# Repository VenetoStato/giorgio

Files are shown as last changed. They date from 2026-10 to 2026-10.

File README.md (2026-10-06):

<div align="center">

# GIORGIO

**An open, mobile two-armed service robot. It sorts, carries, docks to charge itself, and makes espresso.**

*We couldn't build the parts. So we bought them, and made them work together.*








<a href="https://github.com/VenetoStato/giorgio/releases/download/v0.1.0-design/giorgio_teaser.mp4">
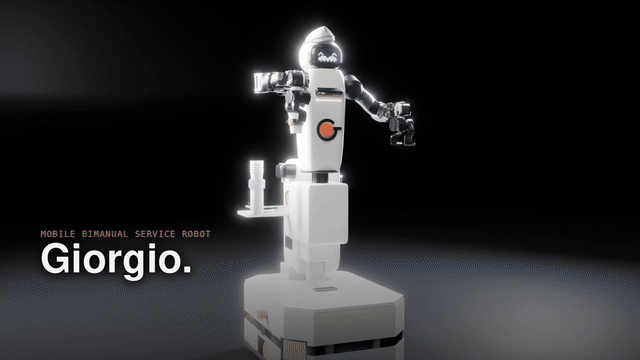
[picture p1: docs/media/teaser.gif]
Giorgio teaser: the robot picks parts, sorts them by colour and drives to the next station (simulation render)
  
</a>

<sub>Simulation render. Click the GIF for the full 68 s teaser. <a href="#videos">More videos ↓</a></sub>

</div>

> [!IMPORTANT]
> **Work in progress: design and simulation only.** Giorgio has **not been built**. Many points are still open:
> type tests, CE certification, the choice of arms, real-hardware validation and more.
> See [Known gaps & open questions](#known-gaps--open-questions). Every number in this repository comes either from
> a manufacturer document or is marked as an estimate or an assumption. Help is very welcome.

Giorgio is a mobile bimanual service robot assembled from **open-hardware projects and certified off-the-shelf
components**:
- Enactic **OpenArm 2.0** arms;
- our own AMR base, built from a SICK, Pilz and ez-Wheel safety chain;
- an Orbbec depth camera and an NVIDIA Jetson.

The structure, shells, power system and software are our own. All of it is public: CAD, calculations, electrical and
safety design, a CE technical-file skeleton, a MuJoCo simulation of the whole robot, the robot software
(GIORGIO-OS) and reinforcement-learning training. Fork it, study it, improve it.

## Contents
[Start here](#start-here) · [What it does](#what-it-does) · [Videos](#videos) · [Architecture](#architecture) ·
[Repository map](#repository-map) · [Quick start](#quick-start) · [Bill of materials](#bill-of-materials) ·
[Customise](#customise-your-giorgio) · [Contribute](#how-to-contribute) · [Known gaps](#known-gaps--open-questions) ·
[Roadmap](#roadmap) · [Status & honesty](#status--honesty) · [Licence](#licence) · [Trademarks](#trademarks)

## Start here

| I want to… | Go to | Time |
|---|---|---|
| **Just look** | the [videos](#videos), the [AMR base datasheet](https://github.com/VenetoStato/giorgio/releases/download/v0.1.0-design/giorgio_amr_datasheet.html) (download it and open it in a browser), the renders in [`amr/renders/`](amr/renders/web) and the [bill of materials](docs/BOM_OVERVIEW.md) | 5 min |
| **Run the simulation** | [Quick start](#quick-start): `make setup && make sim` | 5–10 min |
| **Change the design** | [Customise your Giorgio](docs/CUSTOMIZE.md), then [CONTRIBUTING.md](CONTRIBUTING.md). Starter tasks are labelled [good first issue](https://github.com/VenetoStato/giorgio/labels/good%20first%20issue) | an evening |

Questions and ideas go to [Discussions](https://github.com/VenetoStato/giorgio/discussions). Some file and variable
names are still in Italian; the [glossary](docs/GLOSSARY.md) translates them.

## What it does

All clips are renders of the **MuJoCo simulation** (Blender 4.5 over recorded physics states), not footage of hardware.

<table>
<tr>
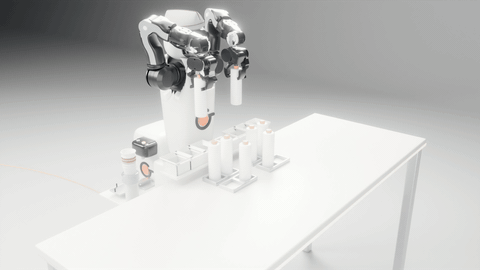
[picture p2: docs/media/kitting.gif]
Kitting: Giorgio loads bottles into its own tray
<td width="33%"><br><b>Kitting.</b> It loads its own tray and uses vision to insert the parts into the kit.</td>
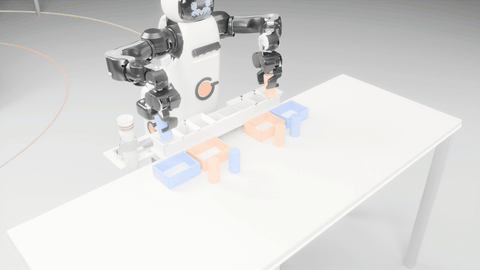
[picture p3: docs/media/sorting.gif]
Sorting parts by colour
<td width="33%"><br><b>Sorting.</b> It sorts parts by colour with a clash-aware two-arm planner.</td>
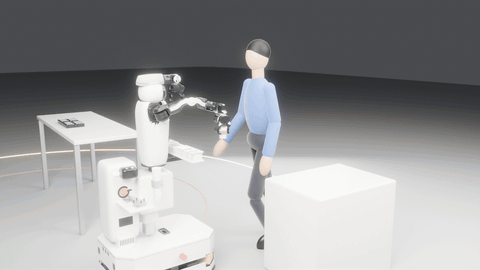
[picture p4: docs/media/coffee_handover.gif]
Coffee hand-over to a person
<td width="33%"><br><b>Coffee hand-over.</b> "Make me a coffee and bring it to Marco": it brews, drives and hands over the cup.</td>
</tr>
<tr>
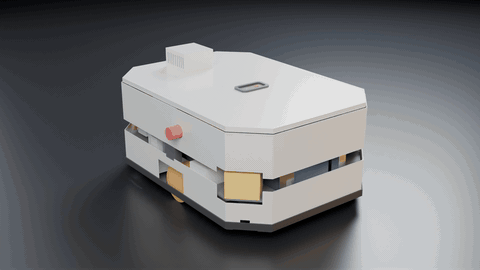
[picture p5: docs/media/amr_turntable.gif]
AMR base turntable
<td><br><b>Own AMR base (rev B4).</b> 780 × 560 mm, turns on the spot, two ez-Wheel safety drives, two SICK nanoScan3.</td>
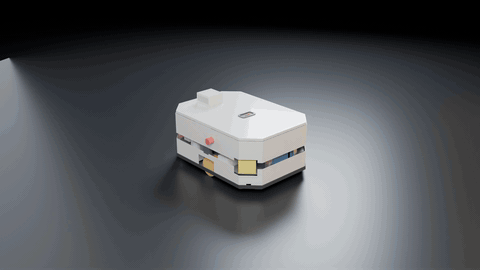
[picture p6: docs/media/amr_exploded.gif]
AMR exploded view
<td><br><b>Every part, off the shelf or laser-cut.</b> 170 CAD parts, 0 interferences, power on the left and safety on the right.</td>
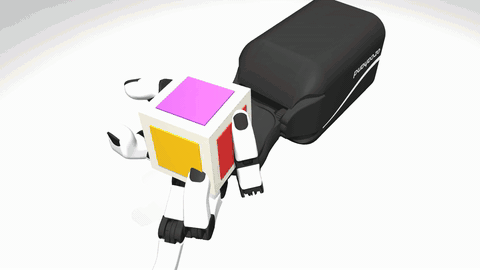
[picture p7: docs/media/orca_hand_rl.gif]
ORCA hand rotating a cube, learned with RL
<td><br><b>Learned skills.</b> An ORCA hand learns in-hand cube rotation with PPO on GPU (236 M steps in 81 min).</td>
</tr>
<tr>
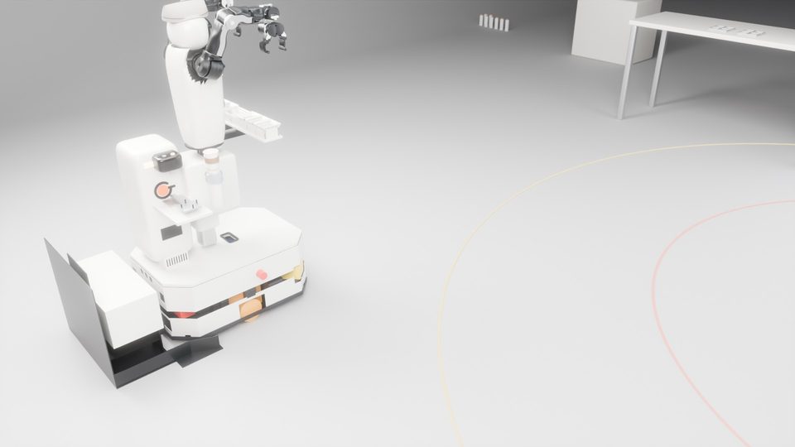
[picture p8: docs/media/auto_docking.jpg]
Giorgio backs onto its charging dock
<td><br><b>Auto-docking.</b> It goes home to charge on its own; the contacts stay dead until it is docked.</td>
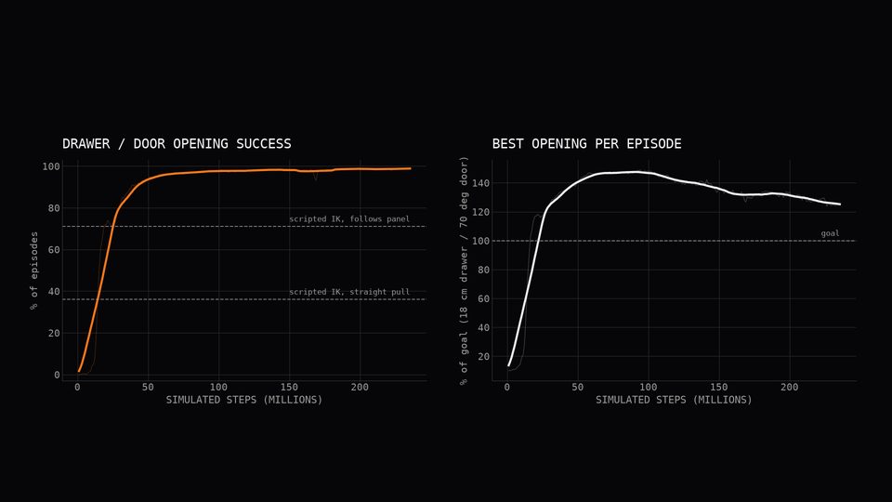
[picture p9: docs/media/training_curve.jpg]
Drawer and door opening learning curves
<td><br><b>Drawers and doors.</b> A policy trained on a plain OpenArm runs unchanged on Giorgio: 90–95 % success, against 71–76 % for scripted IK.</td>
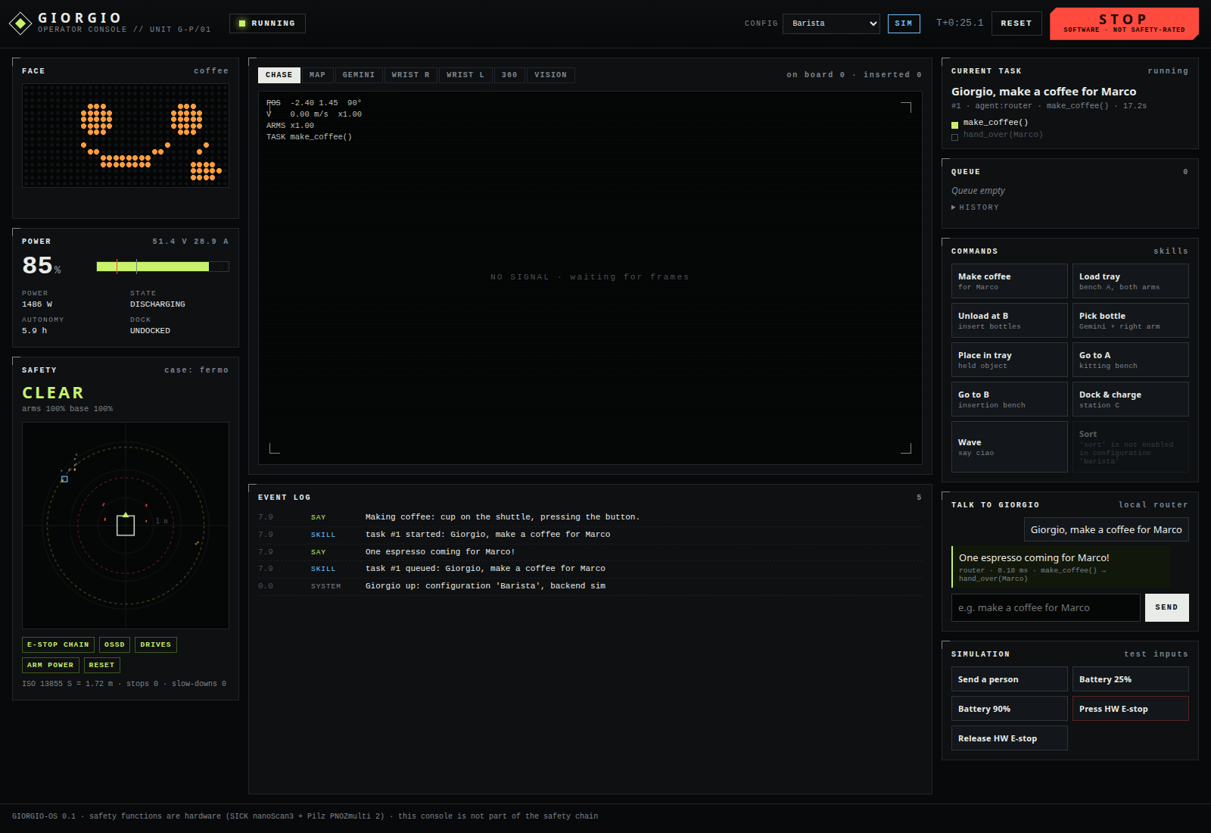
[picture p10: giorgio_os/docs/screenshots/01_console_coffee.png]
GIORGIO-OS operator console
<td><br><b>GIORGIO-OS console.</b> Chat, skills, a live energy budget and safety state, with the same code for sim and robot.</td>
</tr>
</table>

## Videos

Full-HD (1920×1080) videos of the simulation, attached to the
[v0.1.0-design release](https://github.com/VenetoStato/giorgio/releases/tag/v0.1.0-design) (CC BY 4.0):

| Video | Length | What you see |
|---|---|---|
| [Teaser](https://github.com/VenetoStato/giorgio/releases/download/v0.1.0-design/giorgio_teaser.mp4) | 1:08 | the whole idea in one minute |
| [Components](https://github.com/VenetoStato/giorgio/releases/download/v0.1.0-design/giorgio_components.mp4) | 0:57 | the parts and the own AMR base: exploded views, batteries, power and safety, the dock |
| [Activities](https://github.com/VenetoStato/giorgio/releases/download/v0.1.0-design/giorgio_activities.mp4) | 0:51 | loading the tray, vision-guided insertion, slowing down for people, sorting, going home to charge |
| [Training](https://github.com/VenetoStato/giorgio/releases/download/v0.1.0-design/giorgio_training.mp4) | 1:08 | an ORCA hand learns to turn a cube; an OpenArm learns drawers and doors, then runs on Giorgio |
| [Customisation](https://github.com/VenetoStato/giorgio/releases/download/v0.1.0-design/giorgio_customisation.mp4) | 1:06 | LED faces, hats, four setups (grippers, ORCA hands, budget hands, coffee module) |
| [Full film](https://github.com/VenetoStato/giorgio/releases/download/v0.1.0-design/giorgio_full.mp4) | 4:05 | everything above, in one cut |

The videos are built by [`render/video_series.py`](render/video_series.py). Vertical 9:16 cuts are still to do (see the
[issues](https://github.com/VenetoStato/giorgio/issues)).

## Architecture

```mermaid
flowchart LR
  subgraph BASE["Own AMR base (amr/), rev B4"]
    BAT["2× Discover 48 V LFP<br/>3.07 kWh"] --> PWR["Power: fuses, K0 contactor,<br/>Mean Well DC-DCs"]
    DOCK["Dock: RoboPad contacts<br/>+ NPB-750 charger"] --> BAT
    PWR --> DRV["2× ez-Wheel SWD 125<br/>safety wheel drives"]
  end
  subgraph SAFE["Safety chain (deterministic, certified parts)"]
    SCN["2× SICK nanoScan3<br/>protective fields"] --> PNOZ["Pilz PNOZmulti 2<br/>safety controller"]
    ES["E-stops · key selector<br/>enabling pendant"] --> PNOZ
    PNOZ -->|"STO / SLS"| DRV
    PNOZ -->|"K1/K2 contactors"| ARMPWR["Arm 24 V bus"]
  end
  subgraph SUP["Superstructure (cad/)"]
    ARMS["2× OpenArm 2.0<br/>+ grippers / ORCA / AmazingHand"]
    VIS["Orbbec Gemini 336L<br/>+ wrist cameras"]
    COF["Coffee module + tray"]
    JET["Jetson Orin NX"]
  end
  subgraph SW["Software, sim and training"]
    OS["GIORGIO-OS (giorgio_os/)<br/>HAL · skills · energy · NL agent · console"]
    SIM["MuJoCo 3.8 simulation<br/>giorgio_v5.py, giorgio_model.py"]
    RL["RL training<br/>rl_mani/ · rl_openarm/ (mujoco_warp)"]
  end
  ARMPWR --> ARMS
  PWR --> JET
  JET --- OS
  OS <-->|"sim backend"| SIM
  OS -.->|"real backend (stubs)"| ARMS
  RL -->|"policies"| OS
  OS -.->|"status only, never in the safety path"| PNOZ
```

**Design rule:** every safety function runs on certified, deterministic hardware: scanners, a safety controller and
safety drives. No machine-learning model sits in the safety path, as the EU Machinery Regulation 2023/1230, Annex I
requires. Details: [`amr/electrical/`](amr/electrical) and [`amr/ce/`](amr/ce).

## Repository map

| Folder / file | What's there | Status | Main entry point |
|---|---|---|---|
| [`amr/`](amr/README.md) | **Own mobile base**:<br>• CAD (170 parts) and calculations<br>• electrical + safety package<br>• CE file skeleton<br>• industrialisation plan and certainty audit | design rev B4, checks pass | `amr/amr_cad.py`, `amr/amr_calc.py`, `amr/electrical/check_amr.py` |
| [`cad/`](cad/README.md) | Superstructure CAD (CadQuery):<br>• parts and bolted joints<br>• validator<br>• STEP/STL exports | design; base-adapter parts belong to an earlier base variant | `cad/validate.py` → `cad/VALIDATION.md` |
| [`electrical/`](electrical/README.md) | Superstructure power and safety design, netlists, BOM generator | design; base variants archived | `electrical/calc.py`, `electrical/make_bom.py` |
| `giorgio_v5.py`, `giorgio_model.py`, … (root) | **MuJoCo simulation**:<br>• robot model (official OpenArm MJCF + own base)<br>• missions, IK, vision<br>• people, energy, docking | working in sim | `giorgio_v5.py` (`make sim`) |
| [`giorgio_os/`](giorgio_os/README.md) | **Robot software**:<br>• HAL (sim + real stubs), skills<br>• safety supervisor, energy and mission managers<br>• NL agent, web console | sim backend works; real backend stubs | `python -m giorgio_os.sim_server` (`make console`) |
| [`rl_mani/`](rl_mani/README_IT.md) | RL: ORCA hand in-hand cube rotation (PPO, mujoco_warp) | trained policy included | `rl_mani/train.py` |
| [`rl_openarm/`](rl_openarm/README.md) | RL: OpenArm lift and drawer/door policies, transferred unchanged to Giorgio | trained policies included | `rl_openarm/train.py`, `rl_openarm/run_cpu.py` |
| [`verifiche/`](verifiche) | Simulation checks: docking, arm collisions, shells, box forces | working | `verifiche/aggancio.py`, `verifiche/urti.py` |
| [`render/`](render) | Blender 4.5 render pipeline, LED faces, hats, music, video editing | working (needs Blender) | `render/video_series.py`, `render/run_v19.sh` |
| [`assets/`](assets/shells), [`robots/`](robots) | Shell meshes (OBJ) and arm URDFs | data | `shells.py` |
| [`docs/`](docs) | [BOM overview](docs/BOM_OVERVIEW.md), [customising](docs/CUSTOMIZE.md), [glossary](docs/GLOSSARY.md), base decision, power & certification notes, [Italian summary](docs/README_IT.md) | docs | — |
| [`FEASIBILITY.md`](FEASIBILITY.md) | SDK, driver and licence check for every component, plus the top risks | docs | — |
| [`kickstarter/`](kickstarter), [`launch/`](launch) | Campaign and launch drafts (IT/EN) | drafts | — |
| [`scripts/`](scripts) | `setup.sh`, `fetch_third_party.sh`, `bom_overview.py` | working | `make setup` |
| [`legacy/`](legacy/README.md) | One-off and superseded scripts, kept for history | unmaintained | — |
| `third_party/` (not committed) | OpenArm MJCF, ORCA, AmazingHand, LEAP models at pinned commits | fetched | `scripts/fetch_third_party.sh` |

## Quick start

Tested on Ubuntu 24.04 with Python 3.12. You need git, Python ≥ 3.10 with `venv`, and about 1.5 GB of disk. The
optional parts need more: a GPU for training, Blender 4.5 for renders, and a separate environment for the CAD.

```bash
git clone https://github.com/VenetoStato/giorgio.git && cd giorgio
make setup        # .venv + requirements.txt (MuJoCo 3.8, ...) + third_party/ at pinned commits
make sim          # GUI simulation: the logistics mission (needs a display)
make coffee       # GUI: "Giorgio, make me a coffee and bring it to Marco"
make console      # GIORGIO-OS operator console → http://127.0.0.1:8080
make check        # fast checks, the same as CI (AMR electrical/safety + calculations, syntax)
```

<details>
<summary>Without make (manual steps), headless servers, CAD, renders and training</summary>

```bash
# 1. simulation environment (Debian/Ubuntu: sudo apt install python3-venv git)
python3 -m venv .venv && . .venv/bin/activate
pip install -r requirements.txt && pip install --no-deps -e giorgio_os
scripts/fetch_third_party.sh                       # ~400 MB; --minimal = OpenArm only (~30 MB)

# 2. run
MUJOCO_GL=egl PYTHONPATH=. python giorgio_v5.py                                  # GUI
MUJOCO_GL=egl PYTHONPATH=. python giorgio_v5.py --seconds 40 --video video/sim.mp4   # headless → mp4
MUJOCO_GL=egl python -m giorgio_os.sim_server                                     # console
(cd giorgio_os && MUJOCO_GL=egl python -m pytest -q)                              # tests

# 3. checks of the base (PyYAML + numpy only)
python amr/electrical/check_amr.py                 # 242 PASS / 0 FAIL / 11 OPEN
(cd amr && python amr_calc.py)                     # writes amr/CALC.md

# 4. CAD (separate env, ~2 GB): see cad/README.md
python3.11 -m venv cad/.env && cad/.env/bin/pip install -r cad/requirements.txt
make cad-validate && make amr-cad

# 5. renders (Blender 4.5 on PATH or BLENDER=/path/to/blender)
make render-amr

# 6. GPU training (separate env, Python 3.11, NVIDIA GPU): see rl_openarm/README.md, rl_mani/README_IT.md
pip install torch && pip install -r requirements-train.txt
cd rl_openarm && python train.py --task cabinet --envs 4096 --max_minutes 95 --out runs/cX
```
Environment variables: `PYTHON` (interpreter for `make` and `setup.sh`), `CADPY` (CAD env), `BLENDER` (Blender binary),
`MUJOCO_GL=egl` (headless rendering, the default in `make`).
</details>

## Bill of materials

The full robot, grouped by subsystem with part numbers, sources and status, is in **[docs/BOM_OVERVIEW.md](docs/BOM_OVERVIEW.md)**.
It is generated by [`scripts/bom_overview.py`](scripts/bom_overview.py) from [`amr/bom_amr.csv`](amr/bom_amr.csv) and
[`docs/bom.csv`](docs/bom.csv). Component costs only: EUR excluding VAT, prototype quantity 1, no labour.

| Subsystem | Main parts | EUR |
|---|---|---:|
| Base AMR | 2× ez-Wheel SWD 125, laser-cut/bent steel and aluminium frame, sprung castors, covers | 8,317 |
| Safety | 2× SICK nanoScan3 Pro I/O, Pilz PNOZmulti 2 (B0 + 3 × EF 4DI4DOR), contactors, e-stops, pendant | 8,919 |
| Power | 2× Discover DLP-GC2-48V LFP, fuses, main contactor, Mean Well DC-DCs, harnesses | 4,855 |
| Dock | RoboPad contacts, Mean Well NPB-750-48 charger, dock controller | 2,171 |
| Arms & hands | Enactic OpenArm 2.0 bimanual kit (arms, torso, grippers, wrist cameras) + arm power | 6,959 |
| Vision & compute | Jetson Orin NX (reComputer J4012), Orbbec Gemini 336L, fisheye cameras, LED face | 2,335 |
| Structure & shells | column, brackets, tray, PA12 shells, fasteners | 1,476 |
| Coffee module | 24 V capsule machine, cup shuttle, coffee power | 1,025 |
| **Total (barista configuration)** | 171 rows; 67 % of the value from documented prices, the rest are estimates waiting for quotes | **36,056** |

## Customise your Giorgio

Giorgio is meant to be remixed. [docs/CUSTOMIZE.md](docs/CUSTOMIZE.md) explains how to:
- change the base dimensions ([`amr/amr_params.py`](amr/amr_params.py));
- swap the arms or hands (gripper / ORCA / AmazingHand / LEAP);
- change the LED face, hats, tray and coffee module;
- re-run the checks and renders;
- re-train a skill.

## How to contribute

1. Look at the [good first issues](https://github.com/VenetoStato/giorgio/labels/good%20first%20issue) or
   [help wanted](https://github.com/VenetoStato/giorgio/labels/help%20wanted), or open an issue/discussion with your idea.
2. Fork, create a branch, change things, and run `make check` plus the checks of the area you touched.
3. Open a pull request. The template asks for the check results and the sources of any technical value.

Rules that matter:
- Every purchased-part value needs an official source, tagged SOURCED / SECONDARY / ESTIMATE / ASSUMED.
- Safety stays deterministic and certified.
- No manufacturer PDFs in git.

The details are in [CONTRIBUTING.md](CONTRIBUTING.md). Please follow the [Code of Conduct](CODE_OF_CONDUCT.md).
Security or safety-design concerns go through [SECURITY.md](SECURITY.md).

## Known gaps & open questions

What is **not** done or not certain yet. Each item has its source:
- **Arms decision** (owner). OpenArm 2.0 is open and cheap, but it has no brakes, no STO and no safety-rated
  speed/force. That makes it non-collaborative: no certified hand-to-hand hand-over and no CE as-is (gap G1 in
  [`amr/ce/GAPS.md`](amr/ce/GAPS.md)). The alternative is a certified cobot on 48 V DC (variant "C48": UR e-Series /
  Kassow), or a brake retrofit of OpenArm.
- **CE gaps** ([`amr/ce/GAPS.md`](amr/ce/GAPS.md)):
  - safety requirements spec and PL calculations (SISTEMA) not written;
  - coffee machine without a DoC or food-contact declaration;
  - Wi-Fi module and EN 18031 not done;
  - supervisory function and safety logging not implemented;
  - producer registrations not done;
  - the SS1-t ramp-failure residual is open.
- **Type tests TP-01…TP-23** are planned but not run ([`amr/ce/TEST_PLAN.md`](amr/ce/TEST_PLAN.md)). They cover stopping
  distances, personnel detection, EMC, short-circuit current (TP-14) and payload.
- **Certainty audit** ([`amr/CERTAINTY.md`](amr/CERTAINTY.md)). Of the 82 BOM rows, 32 have only a price and need a
  quote, and 1 is a gap. Of the calculation inputs, 2 are gaps (gripper length, coffee machine power) and 28 wait for
  type tests. In the netlist, the battery short-circuit current is unpublished, which leaves 11 OPEN rows.
- **Documents still to fetch or buy** ([`amr/DOWNLOAD_LIST.md`](amr/DOWNLOAD_LIST.md)): the Pilz certificate, the
  Discover UN 38.3 summary, EN 60204-1 / DIN VDE 0298-4, and EN ISO 3691-4.
- **Purchased-part interfaces** in the CAD are partly datasheet envelopes or ASSUMED holes, not vendor STEP files
  ([`cad/VALIDATION.md`](cad/VALIDATION.md)). The superstructure CAD in `cad/` still carries adapter parts of an earlier
  base variant.
- **Software**:
  - the ROS 2 node and launch files are not written;
  - the real-hardware backend of GIORGIO-OS is stubs;
  - 4 of the 29 GIORGIO-OS tests (sim skills: pick into tray, auto-dock, safety stop, chat navigation) have failed
    since the switch to the rev B base;
  - the Claude planner is untested against the live API.
- **Sim ↔ CAD drift**: part of the base geometry in `giorgio_model.py` (castors, wheels) is typed by hand and differs
  slightly from `amr/amr_params.py` (see [docs/CUSTOMIZE.md](docs/CUSTOMIZE.md)).
- **Sim-to-real**: the RL policies use privileged simulator state for the object pose. Nothing has run on hardware.
- **Media**: vertical 9:16 cuts for social media are missing.

## Roadmap

1. **Decide the arms** (OpenArm R&D variant vs a certified 48 V cobot) and freeze the superstructure on the rev B4 base.
2. **Prototype**: buy the long-lead parts (ez-Wheel, nanoScan3, PNOZ, batteries), build the base, and bring up the
   safety chain on the bench.
3. **CE type tests** TP-01…TP-23 with an Italian lab, the SISTEMA PL calculations and the technical file.
4. **ROS 2 bring-up**: base driver, scanners, Nav2 with the docking server, OpenArm `ros2_control`, and the GIORGIO-OS
   real backend.
5. **Skills on hardware**: teleoperation data, then imitation / RL fine-tuning; validate the policies sim-to-real.
6. **Community**: vertical videos, translations, a web CAD viewer, more hands and modules.

## Status & honesty

| | Simulated / designed | Verified on hardware |
|---|---|---|
| Mechanics (CAD, interferences, tipping, bolt loads) | yes: CadQuery + checks | no |
| Electrical and safety design (fuses, contactors, PL targets) | yes: netlists + 242 automated checks | no |
| Robot behaviour (kitting, sorting, coffee, docking) | yes: MuJoCo 3.8 with official arm models | no |
| Learned skills (cube rotation, lift, drawers/doors) | yes: GPU PPO, evaluated on 50–100 episodes | no |
| Purchased-part data | from manufacturer documents where tagged SOURCED; otherwise marked | n/a |
| Prices | 67 % documented, the rest estimates | no quotes yet |

The renders and videos show the simulation. Where a value is an estimate, the file says so. If you find a number
that is wrong or unsourced, please [open an issue](https://github.com/VenetoStato/giorgio/issues/new/choose).

## Licence

- Software: [Apache-2.0](LICENSE).
- Hardware and CAD: [CERN-OHL-S-2.0](LICENSE-HARDWARE).
- Documents, renders and videos: [CC BY 4.0](LICENSE-DOCS).

Third-party models keep their own licences and are not redistributed here (see [NOTICE.md](NOTICE.md)):
- OpenArm: Apache-2.0;
- ORCA Hand: CC BY 4.0 (description MIT);
- AmazingHand: CC BY 4.0 / Apache-2.0;
- MuJoCo Menagerie LEAP hand: per its own licence.

## Trademarks

Giorgio is an independent design concept, not affiliated with, sponsored or endorsed by any company named here.
Component names are used only to identify compatible parts. OpenArm is a project of Enactic, Inc. SICK and nanoScan3
are trademarks of SICK AG. Pilz and PNOZ are trademarks of Pilz GmbH & Co. KG. NVIDIA and Jetson are trademarks of
NVIDIA Corporation. Orbbec and Gemini are trademarks of Orbbec. ORCA Hand is a trademark of ORCA Dexterity, Inc.
AmazingHand is a project of Pollen Robotics. **Ferrari** is a trademark of Ferrari S.p.A. **Fiat** and **Panda** are
trademarks of FCA Italy S.p.A. (Stellantis). The teaser line *"Not a Ferrari. A Fiat Panda."* uses them only as a
comparison. All other names are trademarks of their respective owners. See [NOTICE.md](NOTICE.md).

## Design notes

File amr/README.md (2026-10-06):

# Giorgio AMR: our own mobile base (design rev B4, 2026-10-05)

Giorgio's own mobile base. It is built from certified safety modules plus laser-cut, bent and bolted parts. It turns on the spot,
carries and powers the whole robot, and docks to charge by itself. **Rev B has no waist joint** (owner decision): the 15 mm top deck
is the superstructure flange, at the same height as before (z = 353 mm). Everything above it is unchanged: torso, arms, head, coffee
module and tray.

Status: **design, not built.** Rev B4 (`CAD_REV_B4.md`) implements the fixes of the certainty audit (`CERTAINTY.md`). The CAD has
170 parts, 0 interferences and 0 keep-out violations (24 keep-outs × all parts, 3,608 pairs); castor travel 0 overlaps; the
superstructure fits. Calculations: 53 PASS / 7 WARN / 1 FAIL (the FAIL is "OpenArm holding a cup by friction", so objects travel in the
tray). Electrical checks: 242 PASS / 0 FAIL, 11 OPEN (`electrical/CHECKS_AMR.md`).

**Certainty status (`CERTAINTY.md`, after rev B4) - not every value is documented yet:**
- BOM (82 counted rows): **49 DOCUMENTED, 32 PRICE-ONLY (quote needed), 1 GAP** (harness ampacity table: EN 60204-1 / DIN VDE 0298-4 to buy).
- CALC inputs (116): 51 documented by a manufacturer/standard document, 35 design values, 28 type tests, **2 GAP** (gripper length beyond
  the payload point; coffee machine power - machine not chosen).
- Netlist: **1 GAP**: the B48 prospective short-circuit current (not published) vs the 10 kA IEC breaking capacity of the Mersen HP10M
  branch fuses → 11 OPEN check rows, measured in TP-14.
- Evidence still to fetch by hand or buy: `DOWNLOAD_LIST.md` (Pilz B0 certificate, Discover UN 38.3 summary, two standards).

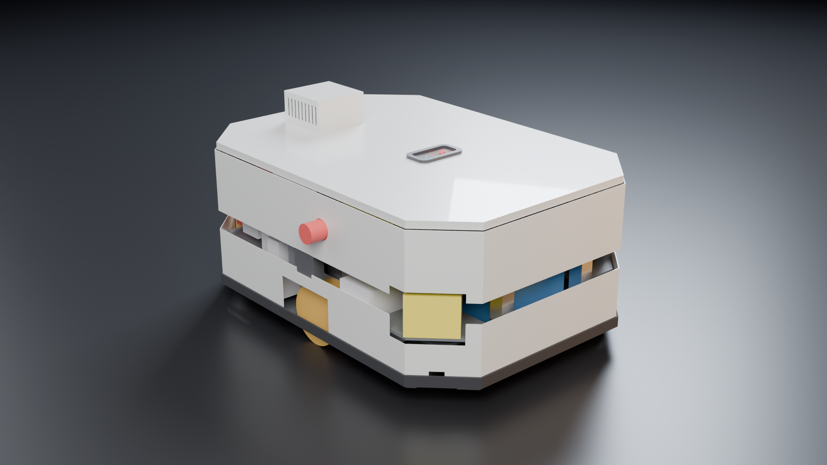
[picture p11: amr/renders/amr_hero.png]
AMR rev B


## Why our own base
No base on the market meets all three requirements:
- payload of at least 85 kg;
- automatic charging confirmed by the manufacturer;
- at least 370 W of power for the superstructure.

The closest, Slamtec Poseidon Standard, publishes neither a dock nor a price (`../docs/BASE_DECISION_2026-10-05.md`). Our own base
gives a documented, certified safety chain for CE, and puts power and docking under our control. At 10 units it also costs less than
a commercial base with the same content (`INDUSTRIALIZATION.md`).

## Architecture (rev B)
| Item | Choice |
|---|---|
| Kinematics | Differential drive: 2 rigid drive wheels at the centre (track 464 mm) + 4 sprung castors **Blickle L-ALST 80K** (D80, 200 kg) at (±275, ±180), each on a HIWIN MGN15 guide with 2 × Gutekunst D-313J-02 springs (28.3 N/mm, 76 N preload, −2.5/+17 mm travel) in the spine/battery gap (`CASTOR_SUSPENSION.md`). Rotates on the spot. |
| Body | 780 × 560 mm with 45° corners, ground clearance 32 mm (3.5 mm under the coaxial drive bodies). 15 mm deck = superstructure flange at z 353, with a 15 mm doubler under the column foot. |
| Drives | 2× ez-Wheel SWD 125 (4:1, brake; coaxial, 196 mm long, 7 kg each). Integrated STO SIL3/PL e; SBC, SLS, SDI SIL2/PL d; safe encoder. 24 V. Each drive runs in its own tunnel fed with room air from under the robot (SWD rated 0…+40 °C). |
| Battery | 2× Discover AES PRO DLP-GC2-48V in parallel: LFP 51.2 V, 3.07 kWh, IEC 62619 / UN 38.3 / CE. Each pack is under 2 kWh, so no EU battery passport is needed. Rev B2: each pack lies on its side with the top cover facing outward and 50 mm free in front of it (Discover manual 805-0027). Over-the-top straps hold it down, and it slides out at the front or rear. |
| Safety | 2× SICK nanoScan3 Pro I/O (PL d) on the front-right and rear-left castor-tower roofs; scan plane 184.5 mm (≤ 200 mm everywhere in the field incl. body pitch: per-band accel/decel limits, CALC §7b), continuous 40 mm slot all round. Safety controller: Pilz PNOZmulti 2 (B0 + 3 × EF 4DI4DOR + ES ETH, `electrical/ELECTRICAL.md`). 3 E-stops, key service disconnect, reset, enabling-pendant socket. |
| Power | B48 bus 40–58.4 V: 100 A NH00 fuse, SW80B contactor + precharge. Traction 24 V from 2× DDR-480C-24 in parallel with ORing and a 27 V clamp. S24 always on. All DDR/DRDN converters are mounted vertically with their Mean Well keep-outs; one DIN position table for CAD and electrical (`electrical/din_layout.md`). K0V 48 V cut-off = Carlo Gavazzi DUB01CD48500V. LYNK II gateway (120 × 135 × 44) on a bracket in the right bay. The Jetson is on the deck at the rear, under cover K06. |
| Dock | Roboteq RoboPad at the rear (z 120, off-centre at y −137, clear of the rear battery keep-out). The dock holds an NPB-750-48 charger (EMC Class B, DIP preset 56.8/53.6 V), a DC contactor, a Carlo Gavazzi DUB01CD48500V over-voltage relay (58.5 V) and a controller; the pads stay dead until the Hall sensor and the CAN handshake both confirm docking. AprilTag + reflector, Nav2 Docking Server. |
| Cooling | San Ace IP68 fans: 2 × 60 mm per side bay (intake above the wheel arch, exhaust on the rear cover), 2 × 40 mm for the centre bay, 1 × 60 mm per drive tunnel. Rated room ambient **0…+35 °C**. |

## Key numbers (`CALC.md`, rev B4)
- **Mass:** base 117.1 kg CAD (120.1 kg with harness; incl. 28 kg batteries). Robot 164.3 kg empty, 172.4 kg loaded.
- **Load split:** each drive wheel carries 40.6 % of the weight (flat, empty); castor rating 200 kg @ 4 km/h vs 121 kg (×3 obstacle factor).
- **Tipping:** worst lateral 4.65 m/s²; SS1 stop SF 3.13; cat-0 stop SF 1.32 (driving poses, WARN, type test TP-03a).
- **Speed:** top speed **1.1 m/s** (the castor rating speed, 4 km/h); safe bands **0.3 / 0.7 / 1.1 m/s** (SLS[1] / SLS[2] / SMS). Rotation on the spot up to 105°/s with the arms parked. Swept radius 440 mm.
- **Protective fields (incl. SICK's 150 mm ground-clearance supplement):** **401 / 613 / 943 mm** from the scanner and **357 / 407 / 457 mm** beside the robot at 0.3 / 0.7 / 1.1 m/s. Rotate-in-place circle R 912 mm. Arm-work field R 2472 mm, 50 mm resolution.
- **Accel / decel per band (scan plane ≤ 200 mm at the field edge):** 1.36/0.79, 1.15/0.69, 0.97/0.61 m/s².
- **Thresholds:** sharp ≤ 10 mm at any speed; 10–20 mm only bevelled ≤ 1:2 at ≤ 0.3 m/s.
- **Runtime:** OpenArm logistics 14.8 h, barista 6.6 h. With Kassow Edge arms (brochure power), 6.4 / 3.3 h.
- **Charging:** 20 → 90 % takes **4.93 h** with the NPB-750-48 (11.3 A); the NPB-1700-48 option 1.89 h.
- **Deck:** 25 MPa and 0.36 mm under 2 g + braking with the lower-bound strip and the doubler (limits 160 MPa, 0.55 mm). Tower roof at the 815 N bump-stop load: 52 MPa.
- **Thermal:** at 35 °C room the SWD tunnel air is 35.9 °C (logistics) / 37.9 °C (sustained 1.1 m/s on 6 %), side bays ≤ 39 °C.

## Operating rules that come from the design (go into the manual and the safety configuration)
1. Drive in reverse only at ≤ 0.3 m/s (SDI + SLS), which is used for docking. The cat-0 brake stop is grip-limited, with a safety factor of 1.32 against tipping in the driving poses, so use SS1 for every stop except power loss.
2. Never drive with the arms extended to the side or rear. Rotate on the spot only with the arms parked.
3. Objects travel in the tray or a form-fit cradle, not held by friction (CALC §8).
4. OpenArm variant: the arms move only while the protective field is clear. Hand-over happens through the tray.
5. Accel/decel limits per speed band (above) in the motion profile; scan plane checked with the test object at every field edge (184.5 ± 5 mm).
6. Floor: sharp thresholds ≤ 10 mm; 10–20 mm only bevelled ≤ 1:2 at ≤ 0.3 m/s. Castor preload 76 N per corner, set on a scale.
7. Room ambient 0…+35 °C; keep the floor under the robot free (the drive tunnels take their air there).

## Cost (`INDUSTRIALIZATION.md`, `bom_amr.csv`; mostly ESTIMATE)
| Variant | 1 unit | 10 units | 50 units |
|---|---|---|---|
| AMR alone incl. dock, materials + assembly | ≈ €26.1k | ≈ €21.9k | ≈ €19.2k |
| Giorgio R&D (OpenArm), materials + assembly | ≈ €38.6k | ≈ €33.2k | ≈ €29.5k |
| Giorgio with certified arms, materials + assembly | ≈ €92.0k | ≈ €82.5k | ≈ €75.1k |

The certified safety parts dominate the cost: 2 SICK nanoScan3 Pro I/O scanners (€2,394.95 each excl. VAT from a German distributor,
checked 2026-10-05) plus 2 system plugs NANSX-AAACZZZZ1 (€265.73 each), the Pilz PNOZmulti 2 station (B0 + 3 × EF 4DI4DOR + ES ETH,
€2,192.17 net + €115.23 terminals) and 2 safety wheel drives (€2.3k each). The castor parts (Blickle L-ALST 80K, HIWIN MGN15R/MGN15H)
have no published price: they are tagged QUOTE in `bom_amr.csv`. One-off CE and engineering costs (NRE) are on top: see `INDUSTRIALIZATION.md`.

## CE (`ce/`)
The route is **module A** (self-assessment, no notified body) under the Machinery Regulation (EU) 2023/1230, which applies from
20 Jan 2027. This holds as long as no machine-learning model performs a safety function.

Harmonised standards that apply:
- EN ISO 12100
- EN ISO 3691-4:2023 (base)
- EN ISO 10218-1/-2:2025 (arms)
- EN ISO 13849-1
- EN 60204-1
- EN ISO 13482 for the barista robot serving the public

Other legislation: RED (Wi-Fi) with EN 18031-1, EMC, and the Battery Regulation.

**Main blocker:** OpenArm has no brakes, which breaks MR Annex III 1.2.6(d). Fix it with brakes or spring balancing on J2/J4, or
switch to certified DC arms. The other gaps are listed in `ce/GAPS.md`.

## Folder map
| Path | What |
|---|---|
| `amr_params.py` | all dimensions, each tagged with its source |
| `amr_cad.py` | CadQuery model → `out/step`, `out/stl`, `out/dxf` (flat parts), `out/exploded`, `out/parts.json`; keep-outs → `out/keepout`, `out/keepouts.json`; checks → `out/interference.json` |
| `integrate.py` | checks the superstructure (`../cad/out/stl`) on the base → `out/integration.json` |
| `amr_calc.py` → `CALC.md` | mass, tipping, drives, energy, charging, safety fields, structure |
| `render_amr.py` → `renders/` | Blender renders: views, exploded, cables, dock, parts sheet |
| `electrical/` | netlist, single-line and safety diagrams, cable schedule, DIN layout, safety functions, checks |
| `ce/` | technical-file skeleton: risk assessment, essential requirements, test plan, DoC draft, manual outline, gaps |
| `INDUSTRIALIZATION.md`, `bom_amr.csv` | Italian suppliers, costs @1/@10/@50, timeline |
| `datasheet/` | product datasheet (HTML) |
| `CONTEXT.md` | shared assumptions for all work streams |
| `CERTAINTY.md` | certainty audit: every purchased row and calculation input with its official source and status (rev B4) |
| `DOWNLOAD_LIST.md` | the few documents that need a manual download or a purchase |
| `CAD_REV_B4.md` | rev B4: SWD at its documented size in drive tunnels, centre bay rearranged, deck doubler, real envelopes, checks |
| `CAD_REV_B3.md` | rev B3: castor suspension in the CAD, DIN layout = electrical, LYNK II real size, K0V/XD3 part numbers, checks |
| `CASTOR_SUSPENSION.md` | castor suspension design (sources, stack-ups, loads) |
| `CAD_REV_B2.md` | rev B2 CAD changes and keep-out checks (installation rules of the batteries and converters) |
| `archive/rev_A/` | rev A (with the waist joint), kept for reference |
| `archive/rev_B1/` | rev B1 `amr_cad.py` / `amr_params.py`, before the rev B2 installation-rule rework |
| `archive/rev_B2/` | rev B2 files (.py, .md, BOM, electrical/, ce/) before rev B3 |
| `archive/rev_B3/` | rev B3 files (.py, .md, BOM, electrical/, ce/, datasheet/, json results) before rev B4 |

Run everything:
```bash
# from the repository root; CAD env = cad/.env (cad/requirements.txt), BLENDER = Blender 4.5 binary
make amr-check                 # check_amr.py (PyYAML only) + amr_calc.py, seconds
make amr-cad                   # amr_cad.py + integrate.py + amr_calc.py in the CAD env (integrate needs cad/out: run make cad-validate once)
(cd amr/electrical && ../../cad/.env/bin/python make_diagrams.py)
make render-amr                # = $BLENDER -b -P amr/render_amr.py -- --view hero --out amr/renders/amr_hero.png
```

## Before pre-production (rev B4)
1. **Close the last GAPs** (`CERTAINTY.md` §3, `DOWNLOAD_LIST.md`): measure the B48 short-circuit current (TP-14, ≤ 10 kA for the HP10M
   fuses), buy EN 60204-1 / DIN VDE 0298-4 for the cable table, measure the gripper length, choose the coffee machine; file the Pilz B0
   certificate and the Discover UN 38.3 summary.
2. **Price quotes:** the 32 PRICE-ONLY rows (Discover packs, LYNK II, RoboPad, Albright, Blickle, HIWIN, Euchner pendant, San Ace fans, …).
3. **Vendor CAD:** SWD 125 STEP (cross-section, fixing points, connectors), DIN modules, castor; re-run the checks.
4. **Drawings:** 2D drawings with tolerances for every bolted joint.
5. **Prototype type tests:** TP-01…TP-23 (`ce/TEST_PLAN.md`), incl. TP-05/05b (fields with Z_F, scan plane), TP-11 (heat-run: SWD air ≤ 40 °C at 35 °C room) and TP-14 (Isc, regen with one DSR off).
6. **Arms decision:** brakes on OpenArm, or certified DC arms.

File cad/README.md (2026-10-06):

# Giorgio — mechanical CAD (parametric, validated)

> **Note (2026-10-06):** the current base is our own AMR rev B4 (`../amr/`). The superstructure parts above the deck
> (column, torso, head, tray, coffee module, shells) are unchanged and are re-checked on the new base by `amr/integrate.py`.
> The base-adapter, battery and scanner-bracket parts in this folder (P01, P03–P11, SH01) and the results below belong to
> the earlier AgileX base variants and are kept for reference. Environment: `cad/requirements.txt`.

Parametric CadQuery model of every part we must manufacture for Giorgio (mobile bimanual service robot), with the
purchased parts as datasheet envelopes (or the official mesh), every bolted joint specified, and a headless validator that
checks interference, clearances, fits, fasteners, mass and tipping. Results are in **[VALIDATION.md](VALIDATION.md)**
(regenerated on every run); sources in **[SOURCES.md](SOURCES.md)**; processes and assembly sequence in
**[MANUFACTURING.md](MANUFACTURING.md)**.

Frame and units everywhere: millimetres, robot base frame = MuJoCo `amr` body (origin on the floor at the base centre,
x forward, y left, z up), coffee shuttle retracted ("out"). **Current design: AgileX RANGER AIR base (owner decision 2026-10-03).** The Tracer 2.0 design is archived in git at commit 2660c92.

## How to run

```bash
# from the repository root
# one-off environment (≈2 GB): python3.11 -m venv cad/.env && cad/.env/bin/pip install -r cad/requirements.txt
#   (or: conda create -p cad/.env python=3.11 && cad/.env/bin/pip install -r cad/requirements.txt)
# coffee poses at the 0.69 m shelf (re-record if the sim changes; ~42 MB, git-ignored):
MUJOCO_GL=egl PYTHONPATH=. python giorgio_v5.py --agent "1:Giorgio, fammi un caffe e portalo a Marco" --seconds 100 --record cad/data/rec_caffe_sh069.pkl
cad/.env/bin/python cad/sim_export.py          # read-only: arm meshes + recorded poses (render/logistica_v9 + cad/data/rec_caffe_sh069.pkl) -> cad/data/
cd cad && .env/bin/python validate.py          # build + all checks + exports, ~2.5 min (--no-export, --skip-sweep, --poses N)
.env/bin/python model.py                        # just build and list parts/masses (11 s)
$BLENDER -b -P render_blender.py -- both   # preview PNGs (Workbench)
```

Outputs (git-ignored, regenerated): `out/step/<part>.step` (one per custom/purchased B-rep part), `out/stl/<part>.stl`,
`out/giorgio_assembly.step` (19 MB) + `.stl`, `out/exploded/<part>.stl` already displaced + `out/exploded/exploded.json`
(per part: file, category, material, process, RGB colour, finish suggestion, explode vector, motion group),
`out/bom_parts.csv`, `out/bom_fasteners.csv`, `out/mass_properties.json`, `out/render_*.png`.

Files: `params.py` (all dimensions, each purchased value tagged SOURCED/ESTIMATE/ASSUMED), `geom.py` (Part/Hole model,
superellipsoid B-rep lofts), `model.py` (all parts + joints), `fasteners.py` (ISO tables, bolt solids, geometric checks),
`validate.py` (assembly, checks, loads, exports, report), `sim_export.py`, `render_blender.py`, `mass_budget_before.json` (reference for the before/after table), `BASE_DECISION.md`.

## Results summary — Ranger Mini 3.0 design (VALIDATION.md has every number)

**57 PASS, 18 WARN, 0 FAIL.** The 18 WARN are:
- 10 bolt groups on ASSUMED purchased-part interfaces (rail slot and T-nut type, OpenArm plate/post/top holes, scanner holes, Gemini);
- 3 arm clearances under the 5 mm target (cup ring 2.4 mm, Gemini 3.1 mm, coffee machine 4.4 mm; 0 contacts in 793 poses);
- the plan overhang (scanner pods, tray, coffee shelf);
- the transient CoG while holding 2 × 3 kg (+22.9 mm);
- 3 tipping cases below the 0.5 g target. All are above the 3.3 m/s² floor (2.2 × the 1.5 m/s² commanded limit).

| Check | Result |
|---|---|
| **Payload (Ranger Mini 3.0: 120 kg; target ≤ 96 kg = 80 %, hard ≤ 108 kg)** | **PASS — superstructure 77.2 kg + product payload 8.1 kg (2 × 3 kg in the hands + 2.1 kg tray) = 85.3 kg = 71 % of 120 kg**, margin 34.7 kg |
| Extension CoG vs centre of rotation (±20 mm) | PASS nominal (+1.9, +3.2) mm, CoG 694 mm above the floor; WARN while holding 2 × 3 kg at 300 mm: +22.9 mm (transient) |
| Interference (858 pairs incl. 124 bolts, exact OCC), shuttle positions | PASS, 0 overlaps |
| Holes / ISO 273 / tap drills / engagement / edge distance (198 holes) | PASS |
| Bolt loads (all groups, 10 load cases incl. 0.5 g, +2 g bump, rebound) | PASS; 10 WARN = ASSUMED interfaces |
| body_link0 covered by the shells | PASS 100 % |
| Arm sweep (793 recorded poses: logistics + coffee at the 0.69 m shelf) | 0 contacts; link2 ≥ 10.3 mm from body_link0, ≥ 12.6 mm from the torso shell |
| Dock-receiver zones (front and rear centre, \|y\| ≤ 150, z ≤ 350, outside the body) | PASS — both free, because the AgileX kit position is UNVERIFIED |
| Footprint | WARN: plan envelope 864 × 864 mm with the corner pods (body 720 × 500); tray ±309 mm |
| **Tipping (wheels ±247 × ±182)** | nominal 5.38 / 5.31 / **3.90** / 3.98 m/s² (fwd/back/left/right); work 4.78 / 5.28 / 3.67 / 3.74; worst (arms fwd, 2 × 3 kg at 0.55 m) 4.33 / 5.67 / **3.65** / 3.72 |

**Required motion limits** (lateral is critical with the 364 mm track; worst lateral tip 3.65 m/s²; safety factor ≥ 2.2):
- **Linear acceleration/deceleration ≤ 1.5 m/s²**, e-stop included. The Ranger Mini braking value is not published → measure it (PAYLOAD_TEST_PLAN.md).
- **Lateral (centripetal) acceleration ≤ 1.5 m/s²**, i.e. turning radius ≥ v²/1.5: ≥ 0.67 m at 1.0 m/s and ≥ 1.5 m at 1.5 m/s.
- Speed ≤ 1.5 m/s (the ROS 2 driver default cap).
- Crab and diagonal motion: apply the same 1.5 m/s² vector limit.
- Spin in place: yaw rate ≤ 1.5 rad/s with the arms stowed (the extended-arm tip radius is about 0.6 m).

## Mass budget (kg; before = validated Tracer design, git 2660c92)

| Group | Tracer | Ranger Mini 3.0 | Note |
|---|---|---|---|
| mobile base | 55.0 | 75.0 | counts against nothing; payload 120 kg |
| OpenArm arms + body_link0 | 26.2 | 26.2 | unchanged |
| our 48 V pack 15s 30 Ah | 13.0 | 13.0 | restored (1.44 kWh) |
| electronics | 6.5 | 8.1 | 3 × DDR-480C (2 arm DC-DCs + coffee), S24/CPU/5 V DC-DCs, Orion-Tr 48/48-6 isolated charger from the base 48 V output (1.3 kg), PNOZ, 2 contactors, Jetson module, Ethernet switch |
| column (foot + profile + bracket) | 6.5 (telescopic) | 4.8 (fixed) | the rails are at 345 mm, so only 207 mm of column fits under the torso; no stroke possible |
| adapter plate | 6.0 | 5.9 | 8 mm 6082 on the 2 rails (16 × M5 into T-nuts) |
| shells | 5.0 | 4.3 | aluminium sheet deck cover (cheaper than SLS) + PA12 waist/torso/head/column/coffee covers |
| coffee module + tray | 7.4 | 7.1 | unchanged geometry |
| scanner pods + 2 × nanoScan3 | 1.9 | 1.9 | kept (our safety chain) |
| other (brackets, wiring 2 kg, fasteners) | 8.2 | 6.9 | |
| **robot total** | **135.7** | **152.2** | |
| **superstructure + product payload** | **88.8** | **85.3** = 71 % of 120 kg | |

## What the design is now (Ranger Mini 3.0, z in mm)

| z | Element |
|---|---|
| 0–329 | AgileX RANGER MINI 3.0: body 720 × 500, ground clearance 105. 4 steerable wheels Ø200 at (±247, ±182). Deck plate 329 + 2 T-slot rails 230 mm apart, top at 345 |
| 345–353 | **P01 adapter** 8 mm 6082, 16 × M5 countersunk into slot-6 T-nuts (rail type ASSUMED) |
| 353–470 | battery tray + 15s 30 Ah pack (front); side e-plates (2 × DDR-480C, PNOZ on DIN, K1/K2); rear e-plate (Jetson module, Orion-Tr charger); all under the **SH01 deck cover** (1.5 mm aluminium, powder coated) |
| 353–565 | fixed column: P29 foot + item 80×80 L profile 197 mm + P02 → torso origin at 580, shoulders at 1278 (as validated) |
| 129–331 | 2 × nanoScan3 pods outside the front-right / rear-left corners at (±359.7, ∓359.7), scan plane 180 |
| 474–942 | coffee module (shelf 0.69 m, unchanged); housing from 474; backpack e-plate (coffee DDR-480C, small DC-DCs, switch) hung under the shelf on 3 standoffs |
| 580–1660 | unchanged: OpenArm torso + arms, waist cover, torso shell, head, Gemini, Insta360, chest tray |

## Cost drivers (custom parts, prototype qty 1, EU job shops — ESTIMATE ±40 %, no quotes yet)

| Part | Process | € (est.) |
|---|---|---|
| P01 adapter plate | waterjet 8 mm 6082 + 48 holes / countersinks | 180 |
| P29 column foot | CNC 20 mm | 110 |
| P02 column-to-torso bracket | waterjet 20 mm + 1 CNC set-up (lightening pockets removed for cost) | 150 |
| P03/P04/P05 battery tray, pad, hold-downs | laser + bend, die-cut EPDM | 100 |
| P06/P07/P08/P30 electronics plates | laser 2 mm + PEM | 80 |
| P09 scanner pods ×2 | laser + bend 3 mm | 90 |
| SH01 deck cover | laser + bend 1.5 mm, powder coat (**instead of SLS ≈ 550 €**) | 160 |
| SH02 column cover, SH03 waist cover | SLS/MJF PA12, 2 halves each | 320 |
| SH04a/b torso shell | MJF PA12 2 halves, painted | 450 |
| SH05 head shell | MJF PA12, painted | 140 |
| SH06 coffee housing | SLS/MJF PA12 | 380 |
| P20 tray halves ×2, P24, P26 | MJF PA12 | 285 |
| P17 Insta360 mast | CNC turned + milled | 60 |
| P21 shelf, P22 uprights, P23, P25 | waterjet 6 mm / bent 2 mm | 145 |
| small sheet brackets (P16, P18, P19, P27, P28) | laser + bend | 105 |
| standoffs | catalogue hex standoffs | 25 |
| **total custom parts** | | **≈ 2,800 €** (+ fasteners/inserts ≈ 120 €) |

| Cost-down option | € saved | Impact |
|---|---|---|
| **Done:** deck cover in bent aluminium instead of SLS | ≈ 390 | +1.2 kg; flat-faceted look |
| **Done:** no lightening pockets on P02; catalogue standoffs | ≈ 80 | +0.6 kg |
| Coffee housing as bent aluminium/PC sheet box | ≈ 230 | less organic look |
| Waist cover as bent sheet box | ≈ 150 | look |
| Torso/head shells in MJF instead of SLS and unpainted dyed black | ≈ 200 | finish |
| P29 foot → item standard base plate for profile 8 80×80 (P/N to confirm) | ≈ 70 | ASSUMED availability |
| Mast → standard Ø14 tube + printed foot | ≈ 40 | none |
| **Series (≥ 20 units):** thermoformed ABS shells on 3D-printed moulds | ≈ 50 % of shell cost | moulds ≈ 1.5 k€ |

## Real vs assumed (Ranger Mini 3.0 specific; the rest as in SOURCES.md)

**SOURCED** (manual + ROS params; data in BASE_OPTIONS.md section 0):
- 720 × 500 mm, 75 kg, payload 120 kg, CoG 213 mm, payload centroid at the rotation centre;
- wheels Ø200 at 494 × 364;
- 2 rails 230 mm apart, top 345;
- 48 V 24 Ah; rear output 46–50 V ≤ 15 A / 720 W (cut below 10 %);
- onboard e-stop only;
- price €12,480 excl. VAT.

**ASSUMED / UNVERIFIED:**
- rail profile, slot and T-nut type (16 M5 at 0.6 N·m); rail width 40 mm;
- charging-kit receiver position (front and rear zones kept free) and the kit/NAVIS price and licence;
- braking deceleration;
- peak output current;
- Orion-Tr envelope (fits a 150 × 100 slot? confirm);
- contactor envelope (45 × 60 × 80).

## Proposed changes to the sim model (exact values, metres)

| Item | Sim now (Tracer) | Ranger Mini 3.0 design |
|---|---|---|
| base body | box 0.702 × 0.61 × 0.25, diff drive + casters, 55 kg | **0.720 × 0.500, z 0.105–0.329 (+ 2 rails 0.04 wide at y ±0.115, top 0.345), 75 kg, CoG z 0.213** |
| wheels | 2 drive + 4 casters | **4 steerable drive wheels Ø0.200 at (±0.247, ±0.182)**; 4WS modes (Ackermann, crab, spin); speed ≤ 1.5 m/s; **accel/decel and lateral accel ≤ 1.5 m/s²** |
| base fixed mass (not visual, on `amr`) | 46.2 kg | **46.6 kg at (−0.011, 0.006, 0.445)** (pack, electronics, adapter, pods, deck cover, coffee module, column foot) |
| battery | 15s 30 Ah | unchanged 15s 30 Ah (1.44 kWh) + base 48 V 24 Ah (1.15 kWh); the Orion-Tr charges our pack from the base output; the AgileX station charges the base |
| docking | RoboPad nose 0.406 | **AgileX charging kit (NAVIS); receiver position UNVERIFIED**; assume a rear approach as on the Ranger Air (contacts at the rear face centre, z ≈ 0.12–0.18). Front and rear zones are kept free |
| column | telescopic, stroke 0.15 | **fixed** (`COLUMN_STROKE` 0): profile z 0.368–0.565 (1.05 kg), foot 1.25 kg at z 0.363; torso origin 0.580 unchanged |
| `SCANNERS` | Tracer pods | **(0.3597, −0.3597) −45°, (−0.3597, 0.3597) 135°**, `SCAN_Z` 0.18 |
| shells | skirt + bands + bumper | **removed**; deck cover box 0.718 × 0.498, z 0.329–0.470 (pod corner cut-outs); column cover 0.12 × 0.12, z 0.47–0.54; coffee housing from z 0.474 |
| torso, waist, head, tray, coffee module | | unchanged (torso shell (0.105, 0.105, 0.261) at 0.529; waist 268 × 200; shelf 0.69; `COF_LIFT` 0.020) |
| product payload | | 3 kg per arm, tray 2.1 kg |
| robot mass | 135.7 kg | **152.2 kg**, CoG (−0.002, 0.002, 0.453) |

## Open issues (honest list)

1. **Lateral stability**: the motion limits above are mandatory. Ranger Mini braking is unknown → measure it before integration.
2. **Charging kit**: price, licence, receiver position, current; whether the payload output stays live while docked (our Orion-Tr charges the pack from it); NAVIS dependence.
3. **No external safety input** on the base: our PNOZ stops the arms, but the base stops via CAN only → certification issue.
4. **Power**: the base output is 720 W / 15 A. The Orion-Tr draws ≈ 6 A at 48 V while docked; peaks run from our own pack.
5. **ASSUMED interfaces**: rail T-nut type and allowable, OpenArm holes, post slots, scanner holes.
6. **No column adjustment** (geometric impossibility with shoulders at 1.278 m and the rails at 0.345 m).
7. **Not modelled**: cable routing, the NAVIS computer/lidars if the charging kit requires them.

## Fastener check method (fasteners.py / validate.py)

- **Geometry per bolt** (128): every hole of the stack is a feature on its part; the check transforms them into the base frame and verifies parallel axes (≤ 0.5°), coaxiality (clearance holes: bolt must fit, (d_h − d)/2; tapped/insert/nut: ≤ 0.05 mm), contiguous clamped stack (gaps −0.05…0.25 mm), head seated (washer / counterbore), hole diameters (ISO 273 fine…coarse, tap drill d − P, Kerb Konus bore), engagement Le vs requirement (Al 6082-T6 ≥ 1.25 d, 6063/6060 ≥ 1.5 d, 5754 ≥ 1.6 d, purchased threads ≥ 0.7 d within the datasheet max insertion, inserts ≥ 0.9 L, nuts full height + 1 P protrusion, T-nuts full nut height) and bottoming in blind holes/inserts.
- **Edge distance**: OCC solid classification on growing circles around every hole at mid-depth (part locally cropped): e ≥ 1.2 d0 (EN 1999-1-1 minimum) in metal, wall ≥ insert spec in PA12. Purchased parts are not checked.
- **Loads**: for each joint group, the supported parts (mass/CoG from the CAD) under each load case give force F and moment M at the bolt-pattern centroid; per bolt f_i = F/n + θ × r_i with θ = J⁻¹M (polar), moments the pattern cannot carry (collinear bolts, single bolt) go to a contact-edge lever; tension = component pulling toward the support. Checks: F_V + Φ·T ≤ 0.9 F_proof; slip μ Σ(F_V − (1−Φ)T_i) ≥ 1.25 ΣV, else bolt shear ≤ 0.6 Rm As/1.25; female thread stripping 0.6 Rm·0.75·π d Le ≥ 1.25 (F_V + Φ T); insert pull-out ≥ 1.5 (F_V + T); T-nut allowable ≥ F_V + T. Torque T = 0.2 F_V d is reported per group.

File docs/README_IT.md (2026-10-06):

# Giorgio-P — umanoide su base mobile da componenti reali

Simulazione MuJoCo 3.8 (stesso motore del SolverMuJoCo di Newton), modelli ufficiali dei fornitori, rework solo estetico.

| Parte | Componente reale | Modello in sim |
|---|---|---|
| Braccia + busto | Enactic OpenArm 2.0 bimanuale (7+7 DOF, QDD Damiao) | MJCF ufficiale `third_party/openarm_mujoco/v2` (Apache 2.0), coppie 40/27/7 Nm |
| Mani | Pinza OpenArm (default) / Inspire RH56DFTP (opzione) | MJCF ufficiale / URDF Unitree con mesh originali |
| Base | AgileX Tracer 2.0 (702×610×169 mm, 55 kg) | scatola con massa reale, 4 appoggi nel test di stabilità |
| Colonna | colonna elevabile corsa 400 mm (LINAK/igus) | giunto prismatico |
| Visione | RealSense D435i (testa, collo 2 assi) + D405 (polsi) | camere MuJoCo con FOV/risoluzione reali |
| Sicurezza | 2× SICK nanoScan3 (275°) + Pilz PNOZmulti 2 | `mj_multiRay` sulla scena, contorno appreso, campi ISO 13855 |

## Dipendenze esterne (non nel repository)
- `third_party/openarm_mujoco/` = MJCF ufficiale Enactic OpenArm 2.0 (github.com/enactic/openarm_mujoco, Apache-2.0)
- mani LEAP da mujoco_menagerie, Inspire da unitree_ros (solo opzioni)
- Blender 4.5 per i render (variabile d'ambiente `BLENDER`, altrimenti `blender` nel PATH)

## Comandi
```
# dalla radice del repository, dopo `make setup` (vedi README)
PY=.venv/bin/python
$PY giorgio_real.py --look eva                  # GUI (eva | akira | gits | blame | cyber)
$PY giorgio_real.py --look akira --video video/x.mp4 --seconds 90
$PY giorgio_real.py --hands inspire             # mani Inspire (presa a script NON affidabile, vedi sotto)
$PY stability_test.py                           # analisi di ribaltamento
```

## Risultati (1 ottobre 2026)
- Kitting con pinza OpenArm: 8/8 flaconi (Ø50×160 mm, 0,35 kg) nel kit in 90 s, 0 persi, errore di posa 3–6 mm, ~7 s per flacone per braccio.
- Scanner: campo di protezione 1,72 m (ISO 13855: 1600 mm/s × 0,37 s + 1128 mm), avviso 2,82 m. Con operatore e passante: 3 arresti, 30 s rallentato, 25 s fermo su 90 s.
- Mani Inspire: montate e funzionanti, ma la presa di potenza programmata a script espelle il flacone. Va addestrata con teleoperazione/imitazione (leader arm OpenArm KER).
- Stabilità: vedi `video/stabilita.txt`.

## Versione 2 (2 ottobre 2026): corona sensori, carrello, costi ridotti
- Testa sostituita da **corona sensori fissa**: Insta360 X4 su asta (panoramica 360°, modalità webcam USB) + Orbbec Gemini 336L stereo inclinata di 35° sul banco. Niente collo motorizzato. Telecamere da polso: quelle incluse nel kit OpenArm 2.0.
- Base di default **carrello** (telaio in profilo di alluminio, 4 ruote con freno, 4 piedini stabilizzatori a vite su bracci sporgenti, 25 kg di zavorra). AMR Tracer 2.0 come opzione (`--base amr`).
- Gusci di design come mesh (`shells.py`), usati sia in MuJoCo sia in Blender (`render/blender_render.py`).
- Simulazione: 12/12 flaconi in 90 s, 0 persi, con operatore e passante. Stabilità (carrello): ribalta oltre 7,75 m/s² al lavoro, 4,5 m/s² nel caso peggiore; spinta per ribaltare 233 N a 1,25 m (~290 N con piedini a ±0,50 m).

### Distinta componenti v2 (prezzi senza IVA; "stima" dove non c'è un prezzo pubblico)
| Voce | € |
|---|---|
| OpenArm 2.0 bimanuale con pinze e telecamere da polso (6.000 $ ordine via e-mail) + spedizione/dazi | 5.950 |
| Insta360 X4 (stima prezzo di listino) | 500 |
| Orbbec Gemini 336L (379 $) | 340 |
| Mini-PC con GPU RTX (stima) | 1.400 |
| 2× SICK nanoScan3 Core + Pilz PNOZmulti 2 + relè ed arresto d'emergenza | 4.800 |
| Carrello: profili, ruote con freno, piedini, zavorra (stima) | 900 |
| Colonna manuale: profilo 80×80, slitta, morsetti (stima) | 250 |
| Alimentazione, cablaggi, connettori (stima) | 500 |
| Gusci SLS PA12 verniciati, piccola serie (stima) | 1.800 |
| Montaggio e collaudo, 30 h | 1.500 |
| **Totale Giorgio-P carrello** | **≈ 18.000** |
| Opzione AMR Tracer 2.0 + Jetson AGX Orin al posto del mini-PC + integrazione batteria | + 9.750 |
| Opzione mani LEAP (2× ~2.000 $, CAD solo non commerciale) / ORCA Lite (2× 1.500 $, CC BY 4.0) | + 3.600 / + 2.700 |

## Versione 3 (2 ottobre 2026): AMR che guida da A a B, collisioni vere, testa "cute"
- Base di default: **AgileX Tracer 2.0 fisico** (2 ruote motrici con motori a velocità e coppia limitata, 4 piroette, telaio con collisioni). Missione: stazione A → corsia (scanner in modalità marcia: campi che si allargano con la velocità, arresto per il passante) → aggancio sotto il banco B (pure pursuit + raddrizzamento sul posto; errore tipico 3 mm / 14 mm / 0,4°) → campi da fermo con contorno appreso → kitting sulla posa reale.
- Collisioni di colonna e busto contro l'ambiente; compensazione di gravità fatta dai motori (base libera).
- Testa fissa "cute": guscio tondo, frontale nero lucido con la Gemini 336L dietro, **due occhi = display rotondi GC9A01 1,28"** (~5–10 € l'uno) che guardano la persona più vicina, sbattono le palpebre e cambiano colore con lo stato di sicurezza (azzurro/giallo/rosso). Insta360 sopra la testa.
- Comandi: `giorgio_real.py` (AMR, default) · `--base cart` (carrello fisso).

## Versione 5–7 (notte 2–3 ottobre 2026): Giorgio fa tutto da solo, caffè vero sulla schiena, persone articolate
File principale: `giorgio_v5.py` (modello in `giorgio_model.py`). Comandi:
```
PY=.venv/bin/python
MUJOCO_GL=egl $PY giorgio_v5.py --video video/v8_logistica.mp4 --seconds 185          # ciclo logistico completo (loop)
MUJOCO_GL=egl $PY giorgio_v5.py --agent "1:Giorgio, fammi un caffe e portalo a Marco" --video video/v8_caffe.mp4 --seconds 100
$PY giorgio_v5.py --agent "1:..."                                                     # GUI MuJoCo
MUJOCO_GL=egl $PY giorgio_v5.py --record render/rec_logistica.pkl ; cd render && $PY to_npz.py rec_logistica.pkl logistica
MUJOCO_GL=egl $PY pose_record.py render/rec_pose.pkl                                  # posa da studio per i render
render/run_stills_v7.sh ; render/run_video_v7.sh ; python render/compose.py render/edit_v7.json video/giorgio_presentazione.mp4
```
- **Niente pezzi dal nulla**: i flaconi stanno in un vassoio di kitting sul banco A; Giorgio li trova con la Gemini 336L e li carica da solo (6 nel vassoio frontale con imbocchi svasati da 16 mm, 2 nelle pinze). La posa del flacone in pinza viene stimata (telecamera di polso) e compensata al rilascio: 6/6 nel vassoio entro 7 mm.
- **Ciclo chiuso**: B → visione 8/8 fori (errore 1,8 mm) → 8/8 inseriti → Giorgio torna al punto di attesa davanti ad A; l'operatore con la cassetta svuota B a mano, porta i flaconi in A e li rimette nel vassoio; Giorgio riaggancia. Stato finale = iniziale (video in loop), ~160 s.
- **Caffè vero, integrato sulla schiena**: macchina a capsule commerciale (qualsiasi marca, formato compatto) su mensola dietro la colonna. Il braccio destro prende un bicchiere dalla pila, lo posa sulla navetta (attuatore lineare 150 mm sul supporto tazzina ribaltabile della macchina), preme il pulsante sulla testa della macchina; la navetta porta il bicchiere sotto l'erogatore e lo riporta fuori; il braccio prende il caffè pieno e lo porta alla persona. Tutte le pose verificate con IK (una presa laterale sotto la testa NON è raggiungibile: per questo la navetta).
- **Consegna**: Giorgio si ferma davanti a Marco, allunga il braccio; Marco si avvicina, allunga la mano, prende il bicchiere (la pinza si apre), lo porta alla scrivania e lo appoggia.
- **Persone articolate** (17 pezzi: ginocchia, gomiti, mani, capelli/casco, gilet): camminata con avvio/arresto morbidi, testa che guarda il robot, cassetta, presa con IK a 2 segmenti; cedono il passo al robot (distanza minima persona-robot nel ciclo 0,76 m dal centro base) e ripianificano se bloccate.
- **Frenata**: la velocità in arrivo è limitata dallo spazio di arresto con strappo limitato e ritardo; tolto l'azzeramento brusco dei motori (era la causa dell'"imbarcata"). Beccheggio dinamico in frenata ≈ 0,35° (prima 2,4°); i picchi a ~0,9° sono statici, da bracci in avanti con carico, a robot fermo.
- **Scanner**: contorno appreso solo a base ferma (niente falsi arresti dopo l'aggancio).
- **Baffi**: fissi, diffusore stampato in PETG traslucido con LED dietro (colore = stato: azzurro/ambra/rosso, ambra in modalità caffè). Opzione con 2 micro-servo non usata.

### Distinta componenti v7 (prezzi senza IVA)
| Voce | € |
|---|---|
| Enactic OpenArm 2.0 bimanuale con pinze e telecamere di polso | 5.950 |
| AgileX Tracer 2.0 | 7.500 |
| Orbbec Gemini 336L | 340 |
| Insta360 X4 | 500 |
| NVIDIA Jetson AGX Orin 64 GB | 3.150 |
| 2× SICK nanoScan3 + Pilz PNOZmulti 2 + arresto d'emergenza | 4.800 |
| Vassoio, colonna, staffe | 500 |
| Gusci SLS PA12 verniciati | 1.800 |
| Occhi GC9A01 + LED baffi + striscia LED | 40 |
| Zaino caffè: macchina a capsule + navetta lineare + porta-bicchieri | 250 |
| Stazione di ricarica | 900 |
| Cablaggi e alimentazione | 600 |
| Montaggio e collaudo (35 h) | 1.750 |
| **Costo** | **≈ 28.080** |
| **Prezzo al cliente (margine 30% sul prezzo: 28.080 / 0,70)** | **≈ 40.100** → listino 39.900 (early bird) / 42.900 |

Kickstarter: bozze in `kickstarter/` (campagna IT/EN, script video, post di lancio). Vincoli: serve un prototipo fisico funzionante, niente render fotorealistici spacciati per prodotto, ricompensa massima 8.500 € per progetti dall'Italia (il robot completo è un deposito).

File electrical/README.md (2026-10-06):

> **ACTIVE (owner decision, latest): AgileX Ranger Mini 3.0 + our own 15s 30 Ah pack, charged from the base's 48 V port. The AgileX dock charges both. See ARCHITECTURE.md §17.**
> - Files: `netlist_rangermini.yaml` (generated by `python3 variants.py`), `CHECKS_RANGERMINI.md` (**166 PASS / 1 FAIL**), `power_safety_architecture_rangermini.png/.svg` (`diagram.py --rangermini`).
> - The FAIL is SF3: no external safety input on the Ranger Mini.
> - Standard uses the cheapest parts that pass every check (Orin NX 16 GB, DDR-60L-12, gs_usb CAN, no PNOZ Ethernet). Autonomy P1 / P2 / P3 = 7.2 / 6.5 / 15.9 h.
> - BOM: `python3 make_bom.py netlist_rangermini.yaml base_choice_rangermini.yaml`. Totals exclude the AgileX charging kit (price unpublished):
>   - **standard €31,869**
>   - **lean €30,949**
>   - lean with brewing at the dock €30,195
>   - Cost-down table: `docs/BOM.md`.
> - RB-THERON (§16) and Ranger Air (§15) are archived.

> **ACTIVE (owner decision, latest): Robotnik RB-THERON + our own 15s 30 Ah pack; the Robotnik dock charges both batteries. See ARCHITECTURE.md §16, "Do we have the watts?".**
> - Files: `netlist_rbtheron.yaml` (generated by `python3 variants.py`), `CHECKS_RBTHERON.md` (**165 PASS / 2 FAIL**), `power_safety_architecture_rbtheron.png/.svg` (`diagram.py --rbtheron`).
> - FAILs:
>   - P2 barista 4.9 h vs 6 h;
>   - SF3, because Robotnik documents no payload safety I/O.
> - BOM: `python3 make_bom.py netlist_rbtheron.yaml base_choice_rbtheron.yaml`. **€47,778 sum of parts** (barista, no margin, no labour), including the RB-THERON at €25,950 with its dock.
> - Ranger Air (§15) is archived by the owner.

> **ACTIVE (owner decision, latest): Ranger Air, base-powered 24 V. See ARCHITECTURE.md §15.**
> - Files: `netlist_rangerair.yaml`, `CHECKS_RANGERAIR.md` (122 PASS / 4 FAIL), `diagram_24v.py`, `power_safety_architecture_rangerair.png/.svg`.
> - Run: `python3 calc.py netlist_rangerair.yaml CHECKS_RANGERAIR.md` and `python diagram_24v.py` (needs matplotlib).
> - The 4 FAILs are real:
>   - autonomy P1 / P2 / P3 = 3.0 / 2.8 / 7.9 h against 4 / 6 / 8 h (base battery 0.65 kWh usable + 1.9 kg buffer 0.12 kWh);
>   - SF3, the base stop: no external safety input on AgileX bases.
> - Sim impact: the superstructure energy is drawn from the base battery (`--bat_wh 768`, 0.85 usable). Arm power is 210 W sustained per arm, or 550 W for 5 s from the 1.9 kg buffer. Coffee is 300 W only with the arms parked.
>
> - BOM: `../docs/BOM.md` / `bom.csv`, generated with `python3 make_bom.py netlist_rangerair.yaml base_choice_rangerair.yaml`. **€20,029 sum of parts** (barista, no margin, no labour), **excluding the Ranger Air and the AgileX dock**: their prices are not published, so ask for a quote.
>
> Everything below documents the earlier 48 V own-pack design (Tracer prototype / MiR250 product), kept for reference.

# electrical/: Giorgio power and safety design

| File | What |
|---|---|
| `ARCHITECTURE.md` | The design: single-line diagram, voltage domains, loads with sources, budget and autonomy, battery protection, precharge, regen, safety (PL, stop categories), charging and dock, grounding and EMC, coffee decision, arm certification, open issues |
| `netlist.yaml` | Machine-readable netlist and BOM: parts, MPNs, ratings, prices, branches, fuses, contactors, profiles, safety chains. `assumed: true` marks values that are not verified. |
| `calc.py` | Validation. Run `python3 calc.py` (needs only PyYAML). It writes `CHECKS.md` and exits with 1 if anything FAILs. |
| `CHECKS.md` | Tracer prototype: **172 PASS, 2 FAIL, 11 INFO** (SF3 base stop; P2 barista autonomy 5.6 h vs 6 h) |
| `variants.py` | Generates `netlist_mir250.yaml` (the MiR250 product base, per `cad/BASE_DECISION.md`) and runs calc into `CHECKS_MIR250.md`: **157 PASS, 2 FAIL** (SF2: MiR safe output not documented; P2 barista autonomy 4.4 h vs 6 h) |
| `make_bom.py`, `base_choice.yaml` | Consolidated whole-robot BOM: writes `../docs/BOM.md` and `../docs/bom.csv` |
| `diagram.py` | Draws `power_safety_architecture.svg/.png` (Tracer) or, with `--mir250`, `power_safety_architecture_mir250.svg/.png`, at 1920×1080. Run `python diagram.py`, which needs matplotlib. |

**Both FAILs are real and kept on purpose.**
- **SF3 (base stop)** has no rated element: the AgileX Tracer 2.0 documents no external safety input. See ARCHITECTURE §8.6.
- **P2 barista autonomy** is 5.6 h against the 6 h target with the 30 Ah pack. Mitigation: one 15-minute dock top-up per shift, which gives about 6.4 h. See ARCHITECTURE §4.

**Coffee options.** The default is now B (on board, barista), and it passes. A (230 V inverter) and C (at the dock) are INFO rows. A would fail the pack-current and main-fuse checks.

## Key decisions (short)
1. **Battery (final CAD):** 15s5p LFP 30 Ah from 32700 6 Ah power cells (48 V nominal, 37.5–54.75 V, 1.44 kWh, ≤ 13 kg, 270 × 400 × 75 mm). Cells must be ≥ 1.2 C continuous / 2 C for 10 s. Bought as an IEC 62619 / UN 38.3 certified pack with CAN BMS.
2. **Arm power:** each arm on a regulated 24 V bus (Mean Well DDR-480C-24: 20 A, 30 A for 5 s), because Damiao J4310/J4340P have OVP at 32 V.
   - Safety contactors K1 + K2 (mirror contacts) with precharge on the 48 V feed.
   - ORing plus a 27.5 V shunt clamp on each arm bus for regen.
3. **Protection:** class T main fuse (20 kA DC) and gPV 10×38 branch fuses, because the pack's prospective short-circuit current is about 2.55 kA. Automotive 58 V fuses (1–2 kA) are not adequate on the 48 V bus.
4. **Safety logic:** PNOZmulti 2 with 2 × nanoScan3 and 2 × E-stop. Arms stop with SS1-t (category 1, 0.5 s), then power is removed. Arms have no brakes, so they park on mechanical rests and there is no hand-to-hand handover.
5. **Dock:** 1.2 kW CC/CV at 54.0 V. Contacts (Roboteq RoboPad, 2 poles, 75 A) are live only after a resistor-signature plus wireless handshake. Robot contacts are dead when undocked (ideal diode). The Tracer battery is charged by an onboard isolated Orion-Tr 48/24 at 10 A.
6. **Coffee (barista default):** an on-board 24 V DC capsule machine via a dedicated DDR-480C-24, cut by the PNOZ (remote OFF + K4). The Tracer charging is paused while brewing. Alternative: brew at the dock with a stock 230 V machine, which is the fastest to certify.
7. **Arms for a certified collaborative product:** UR3e with the OEM DC control box (19–72 V DC, PL d Cat 3, brakes) on the same 48 V backbone. OpenArm is OK only guard-only, without handover.

## Proposed changes to the simulation (not applied; owner to decide)

### `giorgio_v5.py`, energy model (lines ~35 and ~631–669)
| Item | Now | Proposed | Why |
|---|---|---|---|
| `--bat_wh` default | `2400.0` | **`1440.0`** | 15s5p 30 Ah = 48.0 V × 30 Ah (final CAD) |
| `P_ELEC` | `40 + 2*4.5 + 5 + 4 + 5 + 6 + 8 + 15` = 92 W | **`101.3`** W at the pack | S24 (2 × 3.9 scanners + 5 PNOZ + 27 contactor coils + 2 beacon) / 0.91 = 45.9. C12 (35 Jetson + 3 Gemini + 5 two UVC fisheyes and hub) / 0.895 = 48.0. L5 (3 + 1.5 + 2) / 0.875 = 7.4. The Tracer's own 15 W electronics move to the Tracer battery (below). |
| Arm power | `p_arm` straight from the pack | **`p_arm / 0.92`** (`ETA_ARM_DCDC = 0.92`) | DDR-480C-24 efficiency |
| `K_CU` | `0.04` for all joints | **per joint**: J1, J2 (DM-J8009P) **0.135**; J3, J4 (DM-J4340P) **0.088**; J5–J7 (DM-J4310) **0.677** W/(N·m)² | P_cu = 1.5·R_ph·(τ/K_t)², with K_t = rated torque / rated current (1.0, 3.6, 1.2 N·m/A) and R_ph = 0.090 / 0.76 / 0.65 Ω (docs.openarm.dev motor table). This is an approximation [A]. |
| `P_ARM_IDLE` | `10.0` per arm | keep `10.0` [A] | 8 drivers at about 1.2 W |
| `P_CHARGE`, charge efficiency | `960.0`, × 0.92 | **`P_CHARGE = 1134.0`**, × **0.98** | Dock charger delivers 21 A × 54.0 V at the contacts. 0.98 covers the ideal diode and cable. The charger's mains-side efficiency is not on the robot. |
| Status text | `"IN CARICA 960 W"` | `"IN CARICA 1134 W"` | |
| Traction | `p_drv / ETA_DRIVE` taken from `BAT` (48 V pack) | take it from a new **`BAT_TR = {"E": soc*768, "cap": 768}`** (Tracer 24 V 30 Ah) together with **15 W** Tracer electronics | The Tracer has its own battery |
| Energy balancing | none | when docked and (`soc() > 0.80` or `BAT_TR` SoC < 0.30): `BAT_TR += 284 W`, `BAT -= 326 W` | Orion-Tr 28.4 V × 10 A at η 0.87 |
| Coffee, if alternative C (at the dock) | `P_HEATER = 1260/0.92` from the robot | **heater not charged to `BAT`**; move the coffee module to the charger post | No mains and no heater on the robot |
| Coffee, barista default B (on the back) | `P_HEATER = 1369.6`, `BREW_X = 30/8` | **`P_HEATER = 326.0`** (300 W / 0.92), **`BREW_X = 180/8 = 22.5`** | 24 V 300 W machine at about 3 min per cup, about 16 Wh from the pack |

### `giorgio_model.py`, `pw_*` parts (lines ~172–180)

Sizes are half-extents in m. DDR sizes come from Mean Well datasheets; the others are [A]. Note that several DIN parts are 125 mm tall: check that they fit under the base shell.

| Part | Now (half-extents) | Proposed |
|---|---|---|
| `pw_battery` | (0.20, 0.11, 0.040) | Use the CAD value: half (0.135, 0.20, 0.0375) at (0.184, 0, 0.2195), 13 kg, 15s5p 30 Ah, 1.44 kWh (`cad/README.md`) |
| `pw_bms` | (0.035, 0.07, 0.012) | remove (integrated in the pack) or keep as the pack's CAN/connector box |
| `pw_dcdc0` | (0.035, 0.045, 0.022) | **2 × DDR-480C-24 side by side: (0.086, 0.065, 0.063)** (171 × 129 × 125 mm, 2.75 kg) |
| `pw_dcdc1` | (0.035, 0.045, 0.022) | **DDR-120C-24 + DDR-120C-12 + DDR-60L-5: (0.059, 0.051, 0.063)** (117 × 102 × 125 mm, 1.24 kg) |
| `pw_contactor` | (0.025, 0.05, 0.022) | **2 × Siemens 3RT2036 + K3: (0.050, 0.065, 0.065)** [A] |
| `pw_pnoz` | (0.02, 0.045, 0.022) | **PNOZ m B0 + EF 4DI4DOR: (0.034, 0.050, 0.060)** [A] |
| `pw_charger` | (0.05, 0.05, 0.022) | **Victron Orion-Tr Smart 48/24-16: (0.065, 0.093, 0.040)** [A] |
| `pw_jetson` | (0.05, 0.05, 0.020) | keep (AGX Orin dev kit is about 110 × 110 × 72 mm, so the half-height should be 0.036) [A] |
| new `pw_fuses` | n/a | class T holder + 8 × 10×38 DIN holders + busbar: (0.09, 0.045, 0.04) [A] |
| new `pw_oring_clamp` | n/a | 2 × DRDN40-24 + 2 × HS100 resistors on the base plate: (0.06, 0.04, 0.03) [A] |
| new `pw_msd` | n/a | SB120 service disconnect, reachable from a service flap: (0.03, 0.04, 0.02) [A] |
| new `pw_estop` × 2 | n/a | Ø40 mushroom buttons on the back of the column at about 1.1 m and on the base rear |

The charger post in the sim (`charger_post`, `charger_plate`, `charger_lamella*`) should become a RoboPad base RPBAS90-100 (2 poles 40.5 mm apart, as in `cad/README.md`). Tighten the dock acceptance in `docked_at_charger()` from ±20 mm to **±5 mm** lateral, the RoboPad tolerance. The measured docking error of ≤ 2 mm still passes.

## BOM
The consolidated whole-robot bill of materials is **`../docs/BOM.md`** (machine-readable copy: `../docs/bom.csv`), generated by `make_bom.py` from the CAD BOM, this netlist and the FEASIBILITY.md swaps.
- Barista default on the Tracer prototype: **€32,258 sum of parts** (no margin, no labour).
- Optional assembly labour: €1,750.

Electrical + safety share from `netlist.yaml` (EUR, indicative):

| Group | EUR |
|---|---|
| Battery pack 15s5p 30 Ah certified (BMS included) [A] | 1,150 |
| DC-DC converters (3 × DDR-480C-24 incl. coffee, DDR-120C-24, DDR-120C-12, DDR-60L-5) | 550 |
| Chargers (dock IC1200-class 650 + Orion-Tr 230) | 880 |
| Safety (2 × nanoScan3 4,600, PNOZ m B0 + EF 800, E-stops + reset 90) | 5,490 |
| Contactors, K3/K4 relays, precharge, ORing, clamps, DC-DC fans, fuses + holders, MSD, connectors (incl. RoboPad 260), wire, busbar, EMC filter, isolated CAN | 1,647 |
| **Total** | **≈ 9,717** |

## Caveats
- Web research was capped. Pilz, Siemens, Littelfuse (current site), Victron, Delta-Q and Blue Sea pages could not be fetched, so their key values are flagged `assumed`. Verify them first (ARCHITECTURE §13–14).
- The PFHd values (except the SICK nanoScan3) are placeholders. Run SISTEMA with the manufacturer libraries.
- This design has not been reviewed by a certified electrical or functional-safety engineer.

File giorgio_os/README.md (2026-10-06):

# giorgio_os

This is the unified software stack for **Giorgio**, the mobile bimanual service robot. It is a typed Python 3.10+ package and is built to run in two places from the same code:

- on the real robot (ROS 2 Humble/Jazzy on a Jetson AGX Orin);
- against the existing MuJoCo simulation in `../giorgio_v5.py`.

It covers the hardware layer (HAL), skills, the mission manager, the safety supervisor, the energy manager, a natural-language agent, YAML configurations and an operator web console.

- Architecture, with a diagram and an API table: [ARCHITECTURE.md](ARCHITECTURE.md)
- Software access per component and recommended part swaps: [../FEASIBILITY.md](../FEASIBILITY.md)

console

## Run it

```bash
# one-time, from the repository root: creates .venv with requirements.txt, installs giorgio_os, fetches third_party/
make setup                     # = scripts/setup.sh

# operator console + simulated Giorgio (from the repository root)
make console                   # = MUJOCO_GL=egl python -m giorgio_os.sim_server  -> http://127.0.0.1:8080
#   options: --config barista|logistics|dexterous|lowcost   --speed 2 (sim speed)   --soc 0.25   --no-humans   --port 8080

# tests (headless, ~40 s)
make test                      # = cd giorgio_os && MUJOCO_GL=egl python -m pytest
```

Things to try in the console:

- Type `make a coffee for Marco` in the chat. Giorgio brews with the backpack machine, drives to Marco and hands over the cup.
- Press **Send a person** while it works. The arms freeze in the protective field (`hold (safety)`), then resume on their own once the person leaves.
- Press **Battery 25%**. When idle, Giorgio goes to the charging station by itself.
- Press **STOP**, then **RESET**. This is the software stop, and it is clearly labelled as *not safety-rated*.
- Switch to the **Logistics** configuration with the selector. Coffee skills grey out and `sort` appears.

### Screenshots

Made with headless Chromium against the live sim (`docs/screenshots/`):

| | |
|---|---|
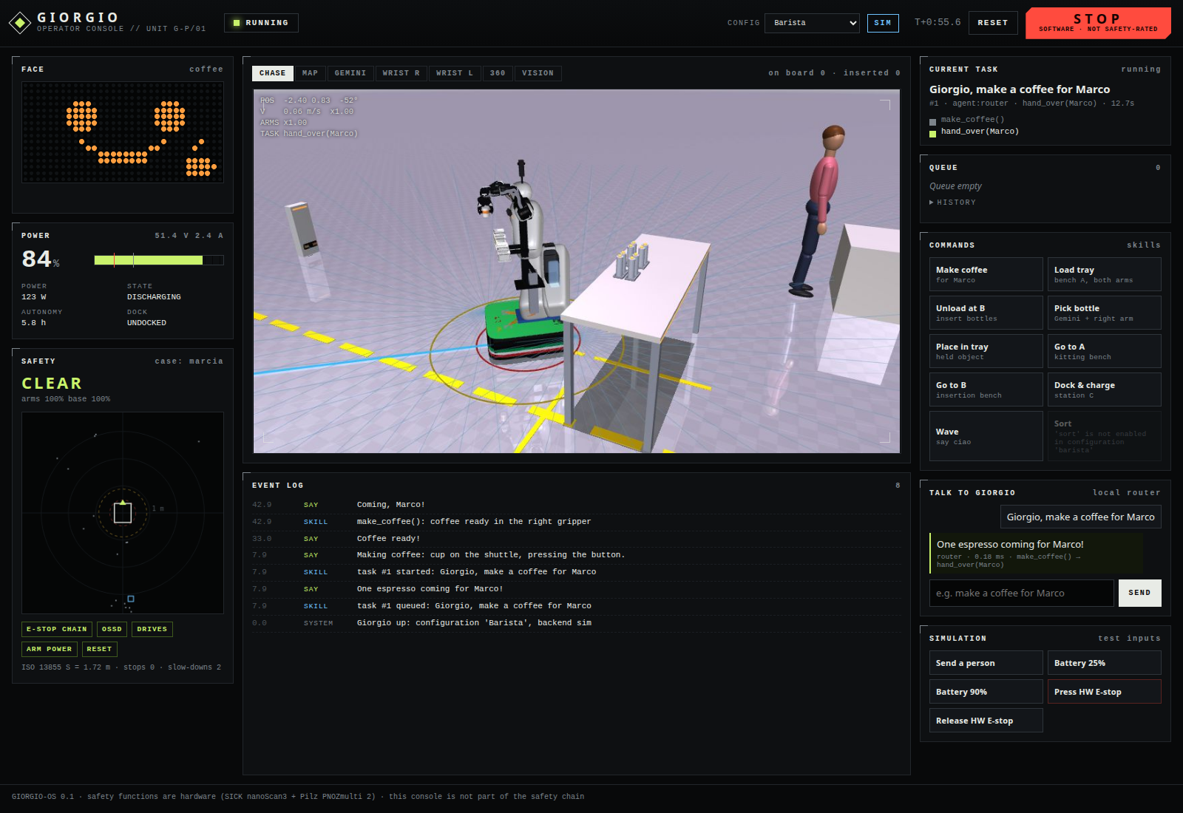
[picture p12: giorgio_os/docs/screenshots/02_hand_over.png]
handover
| coffee Coffee being brewed (heater on: 1.5 kW on the power card) |  Driving to Marco: driving-case scanner fields |
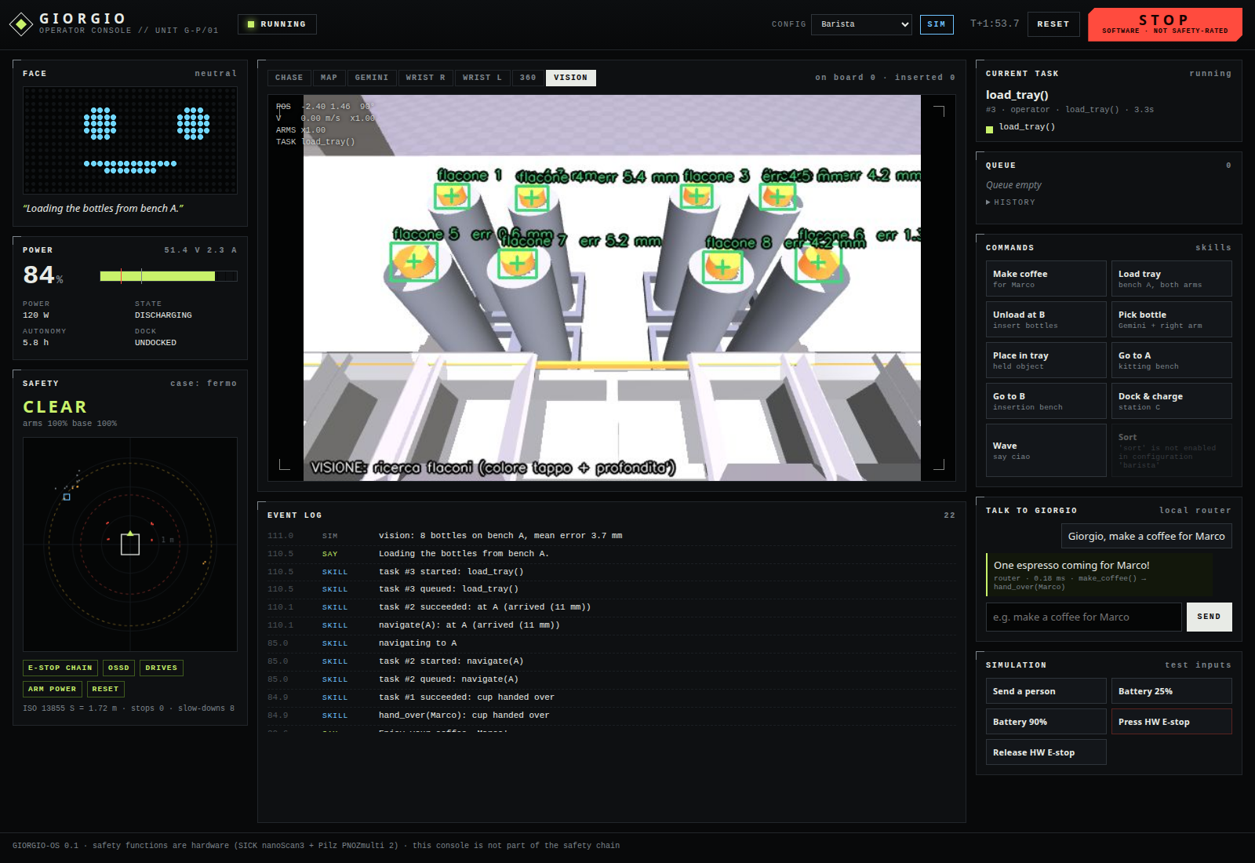
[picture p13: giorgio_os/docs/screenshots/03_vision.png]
vision
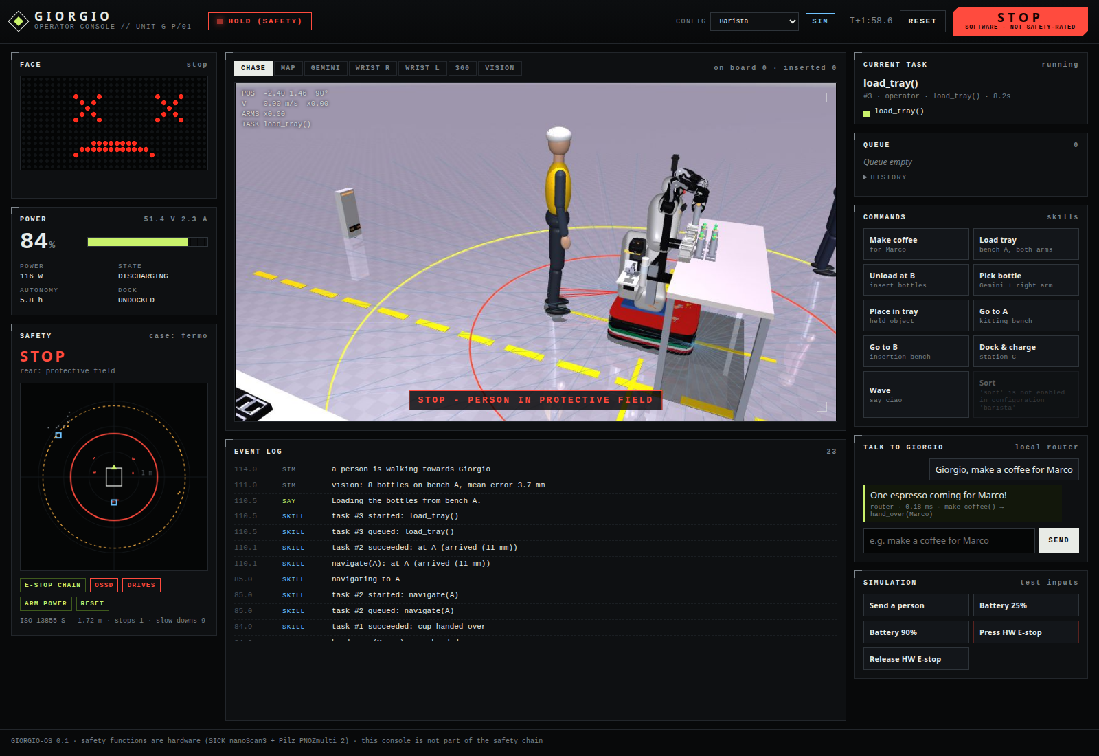
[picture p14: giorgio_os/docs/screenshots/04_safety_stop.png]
stop
|  Gemini 336L vision overlay while loading the tray |  Person in the protective field: arms and base held at 0 |

Phone layout: [docs/screenshots/05_mobile.png](docs/screenshots/05_mobile.png).

## What is real and what is a stub

| Part | Status |
|---|---|
| HAL interfaces (`hal/interfaces.py`) | **done**: one driver per device + planner / perception / world / choreography services |
| **sim** backend (`hal/sim`) | **done**: wraps giorgio_v5 physics, IK, clash-aware planner, Gemini vision, people, energy model, docking |
| **real** backend (`hal/real`) | **stubs**: build fine with no hardware; every method raises `NotBroughtUp` and names the SDK/topic it will use |
| Safety supervisor (SSM, software layer) | **done** and tested; the safety-rated chain is hardware (nanoScan3 → PNOZ) |
| Energy manager (auto-charge, critical abort, coffee guard) | **done** and tested |
| Mission manager (priority queue, software stop, energy guards) | **done** |
| Skills `navigate`, `dock_charge`, `pick`, `place`, `sort`, `wave`, `say` | **done** on HAL primitives only, so they will run on the real robot once the drivers exist |
| Skills `load_tray`, `unload_tray`, `make_coffee`, `hand_over` | **sim only**: run v5's proven choreographies; reported *unavailable* on the real backend until rebuilt from primitives |
| Agent: local router (EN/IT) | **done** |
| Agent: Claude planner | **implemented, OFF by default, untested against the live API** (`agent.llm_enabled: true` + `pip install anthropic` + API key) |
| Operator console + REST API | **done** |
| Configs barista / logistics / dexterous / lowcost | **done**. The `dexterous` config loads the ORCA + AmazingHand models in sim, but scripted grasping is disabled because those hands need a learned policy (`../rl_mani`) |
| ROS 2 node / launch files | **not yet**: roadmap step 1 |

### Tests

There are 29 tests and all pass: `pytest` → `29 passed` in ~40 s on this machine.

| File | What it checks |
|---|---|
| `test_units.py` (13) | ISO 13855 distance; supervisor zones, hysteresis, fail-safe on stale/missing data, relay E-stop, software-stop latch and reset refusal; energy policy; EN/IT router; all configs load with the LLM off |
| `test_real_backend.py` (3) | the real HAL builds without hardware and names its SDKs; choreographed skills are refused on real; configs gate skills |
| `test_sim_skills.py` (5) | **pick-and-place** into the tray (vision → IK → grasp → place); **dock-and-charge** triggered by the energy manager at 25% SoC (contacts closed, SoC rising); **safety**: a person walks into the protective field during pick & place, arms and base go to 0, the joints do not move, then the task resumes and completes; software stop/reset; chat → navigation to B within 10 cm |
| `test_api.py` (8) | index/static, health/status, configs, task submit/validate/complete, chat (router + LLM-off fallback), camera JPEG, software stop/reset endpoint, sim inputs and validation |

### Known limitations

- The Gemini overlay labels (`flacone`, `VISIONE: ...`) come from v5's `Vision.render_overlay` and are still in Italian. Event-log and speech strings are translated.
- On the sim backend, `load_tray`, `unload_tray`, `make_coffee` and `hand_over` are v5 choreographies, so they can't be interrupted half-way as cleanly as the primitives. Cancelling stops the base and the arms and resets coffee mode.
- The sim runs at about 1.6x real time on this machine (the console paces it to 1x). Planning a pick takes about 50 ms of wall time.
- At interpreter exit, MuJoCo/EGL may print `EGL_NOT_INITIALIZED` tear-down warnings. They are harmless.
- The Claude planner has not been exercised against the live API: no key is used in tests and `GIORGIO_OFFLINE=1` is set.

## Changes that would help in `giorgio_v5.py` (not made; the adapter works around them)

The rule was not to modify existing files, so `hal/sim/engine.py` executes v5's source up to the `# ---- uscite` marker, plus the `draw()` function. These small changes upstream would let the adapter use a plain `import`:

1. Move `argparse` and the top-level scene build into a `build_world(args)` function, and guard the main loop with `if __name__ == "__main__":`.
2. Pass `log`, `ag_say` and `system2` in as callbacks instead of using module globals. `system2` shells out to the `claude` CLI; the adapter replaces it with a stub.
3. Split `control_step` into `sense()` / `act(k_arm, k_base)` so the speed scaling can be injected. Today the adapter re-implements `control_step` (about 40 lines) in `SimEngine._physics_step`.
4. Throttle `place_people()` (17 `Rotation.from_matrix` per person per 2 ms step). The adapter calls it at 100 Hz, which makes the sim about 3x faster (≈1.6x real time instead of ≈0.5x).
5. Keep user-facing strings in one table so they can be localised. The adapter translates the Italian `ag_say`/`log` strings to English with regexes.

If the `# ---- uscite` marker or the names the adapter uses (`arms`, `BAT`, `FIELDS`, `Skill`, `route_pose`, `drive_step`, `vision`, …) change, `load_v5_namespace` fails loudly at start-up.

## Roadmap to the first hardware bring-up

Each step ends with a test that can be run on the bench. The real drivers replace the stubs one at a time; everything above the HAL stays as it is.

1. **ROS 2 skeleton (week 1).**
   - Jetson AGX Orin, JetPack 6.2, ROS 2 Humble (OpenArm's stable distro).
   - Implement `RosBridge` (rclpy node + executor thread).
   - Add a `giorgio_os_node` entry point that runs `GiorgioRuntime(backend="real")` at 50 Hz.
   - Add a launch file and a systemd unit.
   - Console reachable on the robot's Wi-Fi.
2. **Safety hardware first (week 1–2).**
   - Wire the nanoScan3 OSSDs, E-stop and contactors to the PNOZ; write and sign the PNOZ program and the Safety Designer field sets.
   - Then implement `PnozRelay` (opto inputs on GPIO, later Modbus TCP) and `NanoScan3` (`sick_safetyscanners2` topics → `ScanFrame`).
   - Bench test: walk into the fields and check the supervisor's zone matches the OSSD LEDs, and that stale data stops the robot.
3. **Base (week 2).**
   - `TracerBase` (tracer_ros2 on CAN0, `/cmd_vel` through twist_mux and a speed-scale filter).
   - Nav2 with a map from the scanners. Then `navigate`, open floor first.
   - Check that the warning and protective fields slow and stop the base through both paths: software scale and PNOZ.
4. **Power and docking (week 3).**
   - 48 V pack with a CAN BMS → `CanBms`; build the dock; `NavDock` on opennav_docking.
   - Repeat the sim's `docktest` (10/10 docks) on the real floor.
   - Turn on the energy manager.
5. **One arm, then two (week 3–5).**
   - `OpenArm` + `OpenArmGripper` via openarm_ros2 (one CAN-FD bus per arm). Gravity compensation and torque limits first.
   - `MoveItPlanner` with the bimanual MoveIt config, then `OrbbecCamera` + `RealPerception` (port v5's HSV + depth pipeline).
   - Goal: `pick` / `place` pass the same assertions as `test_sim_skills.py`, using real detections.
   - Validate the Cat-1 stop sequence (CAN stop → contactor cut) with the arms in a stowed pose.
6. **Face and coffee module (week 5–6).**
   - ESP32-S3 HUB75 firmware + `Hub75Face`.
   - RP2040/micro-ROS shuttle + brew relay + `CoffeeMcu`.
   - Rebuild `make_coffee` from primitives (pick cup → place on shuttle → press → shuttle in → brew → shuttle out → pick). Its choreography flag then goes away.
7. **Hand-over and HRI (week 6+).** `hand_over` with force sensing (motor currents) for the release, people tracking from scanner + Gemini, and a decision on the 360° camera (see FEASIBILITY: UVC fisheye recommended).

Before step 5, freeze the risk assessment (EN ISO 12100) and the safety concept in `../docs/alimentazione_e_certificazione.md`. Nothing in this repository is a safety function.

## Layout

```
giorgio_os/
  ARCHITECTURE.md  README.md  pyproject.toml
  giorgio_os/
    types.py config.py runtime.py sim_server.py
    configs/{barista,logistics,dexterous,lowcost}.yaml
    hal/interfaces.py  hal/sim/{engine,drivers,services}.py  hal/real/drivers.py
    safety/supervisor.py  energy/manager.py  mission/manager.py
    skills/{base,library}.py  agent/agent.py  api/app.py  ui/static/{index.html,app.js,style.css}
  tests/  docs/screenshots/
```

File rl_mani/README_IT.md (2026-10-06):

# rl_mani: rotazione di un cubo in mano con la mano ORCA v2 (RL)

La mano destra ORCA v2 (open source, CC BY 4.0) sta col palmo in su e deve far ruotare un cubo
da 5–6 cm attorno all'asse verticale (+z, in senso antiorario visto dall'alto) senza farlo
cadere. La politica è appresa con PPO su 4096 ambienti paralleli in GPU (mujoco_warp). Non
c'è nessun movimento scriptato: l'andatura delle dita (finger gaiting) è emersa durante
l'addestramento.

## File
| file | cosa contiene |
|---|---|
| `build_model.py` | genera `orca_cubo_rl.xml` a partire dai file ORCA originali, senza modificarli |
| `orca_cubo_rl.xml` | MJCF usato per addestramento, video e Blender (i percorsi delle mesh sono assoluti) |
| `env_orca.py` | ambiente vettorizzato su GPU (mujoco_warp + torch), con ricompensa e randomizzazione |
| `train.py` | PPO compatto scritto per questo progetto (actor-critic MLP) |
| `valuta_e_video.py` | metriche su N episodi, video offscreen e traiettoria `.npz` |
| `grafico.py` | genera `curva_apprendimento.png` da `runs/r1/log.csv` |
| `politica_orca_cubo.pt` | politica addestrata (= `runs/r1/modello.pt`, iterazione 2400) |
| `runs/r1/` | log CSV e checkpoint intermedi (iniziale, 100, 300, 1000) |
| `valutazione/m*.json` | risultati numerici delle valutazioni |
| `prima.mp4`, `dopo.mp4` | video 1920x1080 a 30 fps |
| `traiettoria_dopo.npz` | per ogni frame (30 fps): `qpos`, `xpos`, `xquat` di tutti i body, più `body_names`, `joint_names`, `mjcf` (percorso del modello), `lato_cubo_m` |

## Modello
- ORCA v2 destra, polso bloccato (giunto `right_wrist` rimosso): **16 DOF attuati**
  (abduzione, MCP e PIP per ogni dito; per il pollice CMC, abduzione, MCP e PIP). Gli attuatori
  di posizione sono quelli originali (kp=2, coppia massima ±1 N·m).
- Le collisioni usano primitive al posto delle mesh: capsule per le falangi, box per palmo e
  avambraccio, stimate con la PCA dei vertici delle mesh. Le mesh restano solo visive. Le
  collisioni tra un dito e l'altro sono attive.
- Il cubo è libero, di massa nominale 60 g e lato 5,5 cm, con facce colorate solo visive.
- dt fisico 5 ms, controllo a 25 Hz (8 sotto-passi), cono di attrito ellittico, impratio 2.

## Osservazioni (64)
Posizione dei giunti e target correnti (normalizzati in [-1,1]), velocità dei giunti,
posizione del cubo rispetto al centro del palmo, orientamento del cubo (rappresentazione 6D),
velocità lineare e angolare del cubo, velocità di rotazione attorno a z al passo precedente.
Si aggiunge rumore gaussiano con σ = 0,01.
**Attenzione:** la politica vede lo stato del cubo in modo privilegiato (è il simulatore a
fornirlo). Sul robot reale questo dato non è disponibile così com'è: vedi la sezione sim-to-real.

## Azioni (16)
Incrementi del target di posizione: `target += 0.1 rad · clip(a, -1, 1)`. Il target resta poi
limitato al ctrlrange del giunto.

## Ricompensa (per passo di controllo)
- `+clip(ω_z, -0.5, 1.2)`: velocità di rotazione del cubo attorno alla verticale, ricavata dal
  quaternione (componente twist)
- `-2·d_xy`: distanza orizzontale del cubo dal centro del palmo
- `-0.05·|ω_xy|` (ribaltamento) e `-0.3·|v|` (velocità lineare del cubo)
- `-0.02·|Δtarget|²` normalizzato e `-0.05·Σ τ²`, per avere movimenti dolci e coppie basse
- `-20` se il cubo cade, cioè scende sotto il piano del palmo o si allontana di più di 7,5 cm
  dal suo centro. In quel caso l'episodio termina.

Un episodio dura 16 s (400 passi). Il cubo parte con yaw casuale e un offset di ±1 cm; le dita
partono dalla posa iniziale con un rumore di ±0,08 rad.

## Randomizzazione di dominio (a ogni reset, per ambiente)
Lato del cubo 5,0–6,0 cm, massa 30–120 g (inerzia coerente), attrito 0,5–1,2 (stesso valore su
mano e cubo, perché MuJoCo usa il massimo dei due), kp attuatori ×0,75–1,25, smorzamento dei
giunti ×0,7–1,4. In più, spinte casuali sul cubo (con probabilità 2% per passo, forza
σ = 0,1 N che poi decade) e il rumore sulle osservazioni.

## Iperparametri PPO
4096 ambienti, orizzonte di 24 passi (98 304 campioni per iterazione), 5 epoche, 4 minibatch,
γ = 0,99, λ = 0,95, clip 0,2, value clipping, learning rate adattivo con KL obiettivo 0,016
(partenza 3e-4), entropia 0,002, gradiente limitato a norma 1. Reti MLP 512-256-128 ELU,
separate per attore e critico. Normalizzazione delle osservazioni con media e varianza mobili.
Deviazione standard iniziale 0,6.

## Risultati (run r1)
- Addestramento: **236 M passi di ambiente** (checkpoint usato, iterazione 2400) in **81 minuti**
  di tempo reale su RTX 5070, circa 49 000 passi/s inclusa la PPO. VRAM usata circa 1,9 GB.
- Valutazione su 50 episodi da 10 s, politica deterministica (file `valutazione/m*.json`):

| politica | condizioni | rad / 10 s (media) | giri / 10 s | episodi con caduta |
|---|---|---|---|---|
| non addestrata | con randomizzazione e spinte | 0,04 | 0,006 | 16 % |
| non addestrata | nominale | 0,02 | 0,003 | 8 % |
| non addestrata, stocastica | con randomizzazione e spinte | 0,17 | 0,03 | 42 % |
| **addestrata** | con randomizzazione e spinte | **12,7** | **2,0** | **2 %** (1/50) |
| addestrata | nominale (cubo 5,5 cm, nessuna spinta) | 11,7 | 1,9 | 4 % (2/50) |
| addestrata, 500 episodi | con randomizzazione e spinte | 13,1 | 2,1 | 3,2 % |
| addestrata, 50 episodi da 60 s | con randomizzazione e spinte | 13,8 | 2,2 | 6 % in 60 s |

- Video: in `dopo.mp4` il cubo ruota di 20,7 rad (3,3 giri) in 15 s senza cadere.
- La curva "episodi terminati per caduta" all'inizio è distorta: nelle prime iterazioni gli
  unici episodi che si concludono sono quelli finiti con una caduta.

## Come rieseguire
```bash
PY=${PYTHON:-python}   # ambiente di addestramento: requirements-train.txt (mujoco 3.5, mujoco_warp 3.5, warp 1.12, torch CUDA)
cd rl_mani
$PY build_model.py                                  # rigenera orca_cubo_rl.xml
$PY env_orca.py 4096                                # benchmark (~125k passi di controllo/s)
$PY train.py --envs 4096 --max_minutes 90 --out runs/r2
$PY grafico.py runs/r2/log.csv curva_apprendimento.png
$PY valuta_e_video.py metriche runs/r2/modello.pt --n 50
$PY valuta_e_video.py video runs/r2/modello_iniziale.pt --stocastica --secondi 8 --out prima.mp4
$PY valuta_e_video.py video runs/r2/modello.pt --secondi 15 --out dopo.mp4 --npz traiettoria_dopo.npz
```
`train.py` dipende da `mjlab` (presente nello stesso env) soltanto per `expand_model_fields`.

## Limiti e sim-to-real (in onestà)
- **Stato privilegiato:** la politica conosce posa e velocità del cubo. Per la mano reale serve
  una di queste strade: distillarla in una politica "studente" che usa solo propriocezione e
  storia dei giunti (approccio Hora/RMA), oppure stimare la posa del cubo con una camera
  (D405 sul polso, marker o pose estimation) e addestrare con il ritardo e il rumore di quella
  stima.
- **Attuatori:** la ORCA reale muove le dita con tendini e motori Dynamixel nell'avambraccio.
  Qui ogni giunto è un servo di posizione ideale (kp=2, ±1 N·m). Bisogna identificare la
  risposta reale (attrito dei tendini, isteresi, backlash, latenza del bus, banda) e inserirla
  nel modello, per esempio con una rete attuatore o un modello di tendine. Va randomizzata
  anche la latenza dell'azione, che qui non c'è.
- **Contatto:** le collisioni sono capsule e box, non le superfici reali. La pelle morbida
  della ORCA e la sua cedevolezza non sono modellate, e l'attrito è coulombiano con un unico
  coefficiente. Nel log compaiono avvisi `ccd_iterations` (box-box cubo-palmo): sono innocui,
  ma conviene aumentarli.
- **Comportamento:** la politica ruota a circa 1,3 rad/s, sopra il tetto della ricompensa
  (1,2 rad/s), con movimenti rapidi delle dita. Sul reale andrebbero limitate di più velocità
  e jerk (penalità più alte, filtro sull'azione) per non usurare i tendini.
- La randomizzazione copre dimensioni, massa e attrito del cubo, guadagni, smorzamento e
  spinte. Non copre la gravità inclinata (polso orientato diversamente), forme diverse dal
  cubo, errori di calibrazione dei giunti e il ritardo di osservazione.

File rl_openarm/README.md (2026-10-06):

# rl_openarm — a policy trained for a plain OpenArm 2.0, run unchanged on Giorgio

**Claim we wanted to test:** Giorgio "uses the OpenArm 2.0 stack". So a controller trained for a plain, standalone
OpenArm 2.0 should run on Giorgio's right arm without being retrained. We trained one reinforcement-learning policy on the
standalone arm. Then we ran the same weights on Giorgio, with the same observation and action code.

Everything is in simulation (MuJoCo). Nothing here has run on hardware.

## TL;DR

We trained one policy on the standalone OpenArm 2.0: grasp a cube placed at a random spot on a table and lift it by 10 cm.
It uses PPO on mujoco_warp and the official Enactic MJCF and gripper. Observations are taken in the arm base frame, and
the actions are joint position targets. Then we ran **the same weights, unchanged**, on Giorgio's right arm at Giorgio's
bench.

All results below are 100 randomized episodes each, with noise and latency on:

| policy | standalone OpenArm 2.0 | Giorgio (as built, with its front buffer tray) | Giorgio without the tray |
|---|---|---|---|
| **delivered (v5), current Giorgio (AgileX Ranger Mini 3.0 base, 2026-10-03)** | **99 %** (seed 2: 100 %) | **89 %** (seed 2: 92 %) | **99 %** |
| delivered (v5), previous base (Tracer) | same | 91 % (seed 2: 90 %) | 99 % (seed 2: 97 %) |
| first version (v1) | 99 % | **18 %** | 93 % |

Notes on the table:
- "seed 2" is a second, independent batch of 100 episodes (`--seed 1` in `run_cpu.py`; the JSON files end in `_seed1`).
- Gravity compensation, joint offsets, signs and actuator gains did **not** need any mapping fix. Giorgio attaches the very
  same MJCF, and the policy's interface (the arm base frame) hides where the arm is mounted.
- The real transfer problem was **scene geometry the policy had learned to exploit**:
  - v1 rested its wrist on the table edge, which sits at a different place on Giorgio;
  - v1 also knew nothing about Giorgio's front buffer tray, which sits just in front of the torso.
- The fix was more randomization **in the standalone training scene**: table edge position, plus a low obstacle in front
  of the base. It also adds a penalty for touching the table with the arm links. There was **no training on Giorgio**.
- Of the remaining 9–10 % failures on Giorgio, 13 of 19 are cubes within 6 cm of the tray, which the policy cannot see.

## 1. Is there a pretrained OpenArm policy we could use instead? (checked 2026-10-03, WebFetch only)

| what | URL | usable here? |
|---|---|---|
| Enactic ACT policy, OpenArm 2 *cell* "pick up cube", MuJoCo (LeRobot, ~197 MB, Apache-2.0) | https://huggingface.co/enactic/act-openarm-2-cell-pick_up_cube_mujoco | **No.** It is bimanual (16-dim state/action) and needs 5 RGB cameras placed as in the Enactic cell (ceiling, head L/R, wrist L/R). Giorgio keeps the two official wrist cameras, but it has no ceiling or head cameras in those positions; its chest Gemini 336L sees the bench from elsewhere. |
| Enactic teleop dataset for the same task (LeRobot v3, 30 episodes, 5,405 frames, Apache-2.0) | https://huggingface.co/datasets/enactic/openarm-2-cell-pick_up_cube_mujoco-lerobot | It is data, not a policy. It would be the starting point for an image-based variant (section 4). |
| Official MJCF (what we use) | https://github.com/enactic/openarm_mujoco | Models and scenes only. No policies, no gym envs. |
| Isaac Lab tasks: Reach / Lift / Drawer for a single arm | https://github.com/enactic/openarm_isaac_lab | Reward and observation code exists, but **no checkpoints**, and it targets Isaac Sim, not MuJoCo. |
| LeRobot OpenArm support | https://huggingface.co/docs/lerobot/openarm | Real-hardware drivers only (follower/leader, bimanual). No sim env, no pretrained policy. |
| Community "openarm-rl-best-policy" (PPO, MuJoCo) | https://huggingface.co/qualia-robotics/openarm-rl-best-policy | The repo has only a README. There are **no weights**. |
| Community SmolVLA / ACT fine-tunes on the Enactic cell data | e.g. https://huggingface.co/xXFiEsTaDeAmOnXx/smolvla-openarmv2-cell | All of them are vision-based and bimanual. |

**Verdict:** we found no downloadable policy for a single OpenArm 2.0 arm that runs in MuJoCo from state observations.
So we trained our own (sections 2–3). docs.openarm.dev was only partly checked: its navigation has no learning or simulation
section.

## 2. The policy (trained only on the standalone OpenArm 2.0)

**Robot model.** This is the official Enactic MJCF `third_party/openarm_mujoco/v2/openarm_bimanual.xml`. We remove the
left arm (`scene.py::_openarm_right_only`) and keep the right arm with its official gripper, joint limits, Damiao motor
classes and position actuators (`right_joint1..7_ctrl`, `right_finger1_ctrl`). The model has no gravity compensation,
exactly like the official file. The arm base is fixed on a column in front of a table. No Giorgio part is in this scene.

**Task.** A cube (4–6 cm) is placed at a random spot on the table. The arm must grasp it and lift it.
**Success** means all of the following, within a 6 s episode:
- the cube is at least **10 cm** above where it started;
- it is within 5 cm of the gripper centre;
- this holds for at least **1 s without interruption**.

**Everything the policy sees or commands is expressed in the arm base frame.** That frame is the body
`openarm_right_base_link`, the root of the right-arm chain. It has the same name in both models.

| | content |
|---|---|
| observation (43) | arm joint positions (7) and velocities (7) · gripper position (1) · current joint/gripper targets (8) · gripper centre from forward kinematics (3) · **cube position (3)** · cube minus gripper (3) · lift goal minus cube (3) · last action (8) |
| action (8) | 7 increments of the joint **position targets** (±0.05 rad per step, 25 Hz) + 1 gripper command (open → squeeze) |
| frequency | policy at 25 Hz; physics at 500 Hz (dt 2 ms, implicitfast, elliptic cones, impratio 10, as in Giorgio) |

The cube position is the only "exteroceptive" input. On the robot it is what Giorgio's Gemini 336L pipeline already
outputs (section 4). In training it is corrupted on purpose:
- a constant per-episode bias of ±5 mm (calibration error);
- noise with σ = 3 mm;
- a **latency of 0–3 control steps (0–120 ms)**.

The joint readings are also handled:
- they get noise;
- they have 0–1 step of latency;
- in 30 % of episodes the action is applied one step late.

**Domain randomization** (new values at every reset, per environment):
- cube: size 4–6 cm, mass 30–250 g, friction 0.5–1.2, yaw, position;
- actuators: kp and kv ×0.8–1.2 per actuator, joint damping ×0.7–1.3;
- **gravity compensation** of the arm links: anywhere from 0 to 100 %;
- table height relative to the arm base: −0.40 … −0.32 m;
- from v2 on: the table's front-edge position, and a low obstacle in front of the base (see section 3).

**Training.**
- Algorithm: PPO on **mujoco_warp** with 4,096 parallel environments, on one RTX 5070 (≈ 1.3 GB VRAM).
- Speed: ≈ 78k control steps/s, which is 1.6 M physics steps/s.
- Implementation: the PPO code is reused from `rl_mani`.
- Networks: actor and critic are each an MLP 512-256-128.
- Curve: see the learning-curve figure. The dotted lines mark where training was resumed with a modified reward (v3, v4) or more frequent obstacles (v5).

| phase | what changed | steps | wall time | log |
|---|---|---|---|---|
| v1 (`runs/r1`) | base task, no table-edge or obstacle randomization | 78.6 M (it. 800) | 35 min | `runs/r1/log.csv` |
| v2 (`runs/r2`, from scratch) | + random table front edge (0–0.20 m from the base), + low obstacle in front of the base (50 % of episodes, 4–11 cm high), + penalty −1.5/step when an arm link (not the fingers) touches the table or any arm part touches the obstacle | 44.2 M | 17 min | `runs/r2/log.csv` (first 450 it.) |
| v3 (`runs/r3`, resumed) | v2 lifted the cube to ~50 cm and kept it there. Reward now drops above 16 cm (−8/m) and the goal term is wider | +40.4 M | 22 min | `runs/r3/log.csv` |
| v4 (`runs/r4`, resumed) | stronger overshoot penalty (−25/m): peak lift falls from ~45 cm to ~20 cm | +38.9 M | 18 min | `runs/r4/log.csv` |
| **v5** (`runs/r5`, resumed) = **delivered** | obstacle present in 75 % of episodes instead of 50 % (v4 had lost some robustness to the tray) | +44.4 M | 15 min | `runs/r5/log.csv` |

The delivered policy saw 168 M simulated control steps in 72 min of training. The dips in the curve right after each
resume are partly an artifact: all 4,096 environments restart together, so for a while the only episodes that finish are
failures. The same thing happens at the very start.

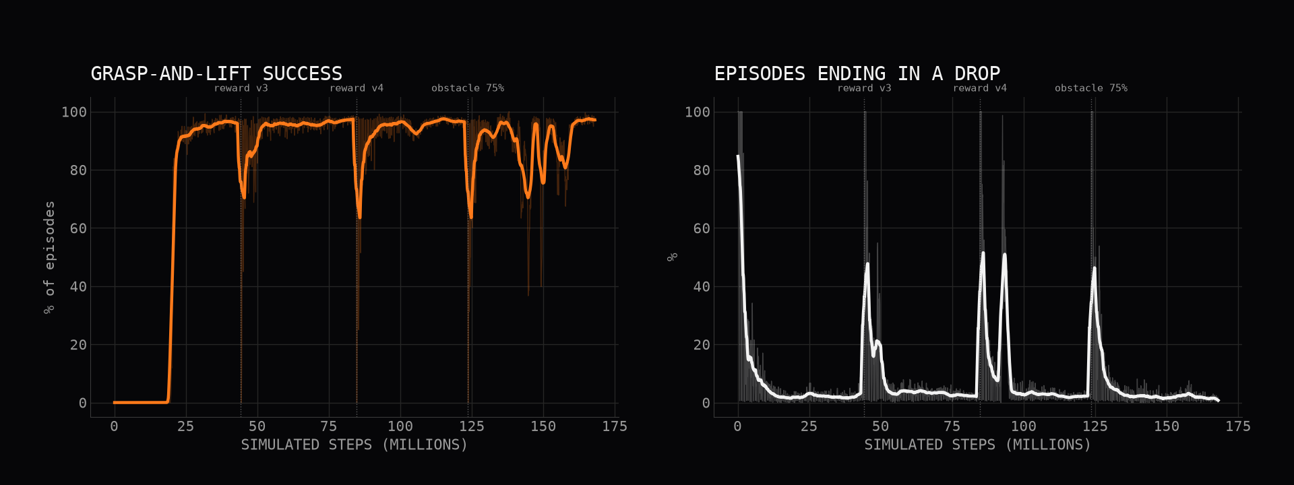
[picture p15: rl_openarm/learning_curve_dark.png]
learning curve


## 3. Transfer test: the same weights on Giorgio

`run_cpu.py` runs the policy in standard MuJoCo on the CPU. It uses the **same** observation and action code
(`policy_io.py`) on two robots:
- **standalone:** the scene above;
- **Giorgio:** built with `giorgio_model.build(hands="gripper", base="amr", fixed_base=True)`. It is the full robot: torso,
  lift column, AMR, left arm, shells and the front buffer tray. The cube sits on the same bench "B" as in `giorgio_v5.py`
  (top at 0.90 m).

The base frame is read from the simulator at every step. On the real robot this would be the TF lookup
`base_link → openarm_right_base_link`. No joint offsets, sign flips or gain changes were needed. The joint names, zero
positions and actuators are identical, because Giorgio attaches the very same MJCF.

What actually differs between the two scenes:

| | standalone OpenArm | Giorgio |
|---|---|---|
| gravity compensation | none (official MJCF) | 100 %, motor-side (`actgravcomp`, counted against the motor torque limits) |
| table under the cube, relative to the arm base | 0.36 m below | 0.378 m below (bench at 0.90 m, shoulders at 1.278 m) |
| table front edge, relative to the arm base | 0.08 m in front | 0.16 m in front |
| obstacles | none | Giorgio's front **buffer tray** (x 0.15–0.23 m, ~10 cm above the bench), torso, left arm |
| base | rigid | the torso rides on the lift column (slightly compliant) |

Every evaluation runs 100 episodes with all of the randomization, noise and latency above. The cube is placed in the
same region of the arm base frame on both robots. 95 % Wilson intervals are given in brackets.

Success rate:

| policy | standalone OpenArm 2.0 | Giorgio as built (with front tray) | Giorgio, tray removed | notes |
|---|---|---|---|---|
| untrained (initial weights) | 0 % [0–7] (50 ep.) | — | — | |
| v1 | 99 % [94.6–99.8] | **18 %** [11.7–26.7] | 93 % [86.3–96.6] | leans its wrist on the table |
| v2 | 97 % [91.5–99.0] | 84 % [75.6–89.9] | 95 % [88.8–97.8] | lifts the cube to ~40 cm |
| v3 | 97 % / 99 % | 84 % / 85 % | 97 % [91.5–99.0] | transient swing up to ~45 cm |
| v4 | 98 % / 97 % | 78 % / 66 % | 98 % [93.0–99.4] | natural motion, less robust to the tray |
| **v5 (delivered)** | **99 % [94.6–99.8] / 100 % [96.3–100]** | **91 % [83.8–95.2] / 90 % [82.6–94.5]** | **99 % [94.6–99.8] / 97 % [91.5–99.0]** | |
| v5, nominal (no randomization/noise/latency, 50 ep.) | 100 % [92.9–100] | 90 % [78.6–95.7] | — | |
| **v5 on the current Giorgio (Ranger Mini 3.0 base)** | (unchanged) | **89 % [81.4–93.7] / 92 % [85.0–95.9]** | **99 % [94.6–99.8]** | no retraining |
| v5 on the current Giorgio, nominal (50 ep.) | — | 94 % [83.8–97.9] | — | |

All rows above the "current Giorgio" rows were measured on the **previous base** (AgileX Tracer, before 2026-10-03).
The Giorgio model was then updated:
- base: AgileX Ranger Mini 3.0, driven as a kinematic mocap target when mobile; fixed in this test;
- also new: deck cover, fixed column, scanner pods, coffee module on the 0.69 m shelf;
- unchanged: arms, torso, 1.278 m shoulder height, bench and front tray.

We re-ran v5 on it **without retraining**, and `scene.py` needed no change. The result is within the statistical noise of
the previous base: 89 % and 92 % now against 91 % and 90 % before, with overlapping intervals. Files:
`valutazione/v5_rangermini_*.json`. `giorgio_transfer.mp4` and `.pkl` were regenerated on the current model.

"a / b" = two independent batches of 100 episodes (seeds 0 and 1).

How the delivered policy moves:

| | standalone | Giorgio (with tray) |
|---|---|---|
| mean peak lift | 15.4 cm | 17.0 cm |
| mean time to success (includes the 1 s hold) | 1.72 s | 2.22 s |

Every number comes from `valutazione/v*_*.json`.

### What went wrong first, and how we found it

1. **First result (v1):**
   - standalone: 99 %;
   - Giorgio without its tray: 93 %;
   - Giorgio as built: **18 %**.
2. **Isolating the factors.** We used the it.-450 checkpoint of v1 and ran 50 episodes per variant, with the same seeds.
   - **Gravity compensation does not matter.** Giorgio scored 72–74 % with gravity compensation motor-side (as built) or
     removed. At an earlier checkpoint, motor-side, passive and removed all gave the same 63 %. The standalone arm scored 94–98 % with no compensation and with Giorgio-style motor-side compensation. We had
     randomized it 0–100 % in training anyway.
   - **Table height does not matter.** The standalone arm with the table at Giorgio's height scored 96 %.
   - **Table edge position explains the whole gap.** Moving only the standalone table's front edge from 0.08 m to Giorgio's
     0.16 m dropped success to 74 %, the same as on Giorgio.
   - A step-by-step trace confirmed it. With Giorgio's gravity compensation switched off, the two robots stay within
     ~1e-3 rad of each other for the first ~10 control steps. They diverge exactly when the policy's link5/link6 start
     resting on the standalone table during the lift. On Giorgio
     there is no table at that spot, so the arm takes a different posture, hits joint limits (j2 at −0.17 rad, j6 at
     +0.79 rad) and stops at 8–9 cm.
   - For the final v1 weights: standalone with table edge 0.16 m and table height −0.378 m scored 93 %, the same as Giorgio
     without the tray.
3. **The tray.** Contact logging on Giorgio as built showed the gripper and forearm repeatedly hitting the tray's walls
   and chamfers (`tray_ch*`). The policy had never seen anything between the base and the cube.
4. **Fix: generic randomization of the standalone scene, not Giorgio-specific training.**
   - The table's front edge moves 0–0.20 m.
   - A low box obstacle 4–11 cm high stands somewhere 0.085–0.235 m in front of the base. The policy cannot see it.
   - A penalty applies when an arm link (not the fingers) touches the table or anything touches the obstacle.
   - The observation and action mapping was not touched. It was already correct: the trace above shows identical behaviour
     once the scene is the same.
5. **Reward shaping.** v2–v4 only fixed motion quality: lifting to 50 cm, then a swing-up. v5 just made the obstacle more
   frequent.
6. **Remaining failures (v5 on Giorgio as built).** 13 of the 19 failures (both seeds) are cubes 0.25–0.29 m from the
   base, i.e. 2–6 cm from the tray wall. There the fingers or forearm still catch the tray. Giorgio's own scripted pipeline avoids this zone (its objects
   sit at x ≥ 0.30 m).

## 4. Does it need vision? What changes compared with a "normal" vision system?

Yes, it needs vision, but only to answer *where is the cube*. The question is which part of the pipeline the learned policy
replaces. There are three levels:

1. **Classical pipeline (Giorgio today, `giorgio_v5.py` / `giorgio_sort.py`).**
   - The Gemini 336L gives colour and depth.
   - Colour segmentation plus the depth of the top face give the object pose.
   - A hand-written planner chooses the approach and grasp poses.
   - IK turns them into joint targets, and the joints follow a scripted trajectory.

   Every step is explicit and debuggable. But each new object or situation needs new code: grasp heuristics, approach
   directions, recovery when the object moves.
2. **Learned policy on state (what we did here).**
   - The vision part is **unchanged**: the Gemini still outputs the cube position, now expressed in the arm base frame.
   - The *planner + IK + scripted trajectory* are replaced by the policy. It closes the loop at 25 Hz, from joint states and
     the cube position directly to joint targets.

   This is why we randomized what vision really delivers: noise, a calibration bias and 0–120 ms latency. Nothing about the
   camera itself changes: same sensor, same segmentation. The interface is the same three numbers per object that the
   classical pipeline already computes.

   Limits:
   - the policy only knows the cube's *position*, not its shape or orientation;
   - it does not know about obstacles it was not trained with;
   - it needs a fresh pose estimate while it moves, so the arm must not hide the cube from the chest camera. A wrist
     camera helps here.
3. **End-to-end visuomotor policy (images in, actions out).** Examples: ACT or Diffusion Policy in LeRobot, or VLA models
   such as SmolVLA / pi0. The policy gets camera images (chest Gemini and/or the wrist cameras) plus joint states, and
   learns perception and control together.

   What it needs:
   - **demonstrations:** typically 50–200 teleoperated episodes per task. The OpenArm leader arms or VR teleop are
     supported by LeRobot. Enactic's cell dataset above has 30 episodes, recorded in MuJoCo.
   - **the same camera placement at training and deployment time**, or heavy randomization of viewpoint, lighting,
     textures and object appearance if it is trained in sim.
   - much more compute per decision.

   What it gives:
   - no hand-written segmentation;
   - it can handle objects with no clean colour or depth cue (transparent, deformable, cluttered).

   Transfer is harder. A policy trained in the Enactic cell sees the cell's cameras and background. On Giorgio the cameras
   are elsewhere, so it would have to be fine-tuned on Giorgio data. Our state-based policy transferred **because** its
   interface (joint states + object position in the arm base frame) does not depend on where the cameras are.

**What an image-based version of this demo would need (plan, not done):**
1. Render the Gemini 336L view (`gemini` camera in Giorgio's model) and the wrist camera during PPO rollouts (MuJoCo
   offscreen, or mujoco_warp batch rendering), with randomized light, bench texture and cube colour.
2. Distil the state policy into an image policy (teacher–student, DAgger): the student gets images + joint states, and the
   teacher supplies the action labels. This avoids collecting teleop data for a task we can already solve with privileged
   state.
3. Alternatively, record ~100 teleop demonstrations on Giorgio, or use our state policy as an automatic demonstrator, and
   train ACT or Diffusion Policy with LeRobot.

Either way, the camera placement used for training must be Giorgio's own. This is the main reason an off-the-shelf OpenArm
visuomotor checkpoint (the Enactic ACT model above) is not "plug and play" on Giorgio, while a state-based one is.

## 5. Files

| file | what it is |
|---|---|
| `scene.py` | builds the standalone OpenArm scene (official MJCF, right arm + gripper) and the Giorgio scene (giorgio_model.build + bench B + cube) |
| `policy_io.py` | the policy interface: constants, observation builder, gripper mapping (shared by GPU training and CPU runs) |
| `env_openarm.py` | vectorized GPU environment (mujoco_warp + torch): reward, randomization, latency |
| `train.py` | PPO (from rl_mani, adapted) |
| `run_cpu.py` | runs the policy unchanged on `--robot openarm` or `--robot giorgio`: evaluation (JSON), video (1920x1080, 30 fps, no overlays), Giorgio-format recording (`.pkl`) |
| `grafico.py` | learning curve (dark style) |
| `check_scene.py` | gripper geometry and forward-kinematics checks |
| `politica_openarm_lift.pt` | **delivered policy** (v5 = `runs/r5/modello.pt`) |
| `politica_openarm_lift_v1.pt`, `_v2.pt`, `_v3.pt` , `_v4.pt` | earlier versions, kept for the comparison in section 3 |
| `valutazione/*.json` | every evaluation: settings, success rate, Wilson interval, per-episode detail |
| `runs/r1..r5/` | training logs (CSV) and checkpoints |
| `learning_curve_dark.png` | learning curve |
| `openarm_standalone.mp4` | the delivered policy on the standalone OpenArm 2.0 (10 s, several episodes) |
| `giorgio_transfer.mp4` | the same weights on Giorgio's right arm, at the bench (10 s, light background; current Ranger Mini 3.0 model, front tray present) |
| `giorgio_transfer.pkl` | the same Giorgio run in the `giorgio_v5.py --record` format (geoms + per-frame xpos/xquat at 30 fps). Convert with `render/to_npz.py` for Blender. |

## 6. How to rerun

```bash
PY=${PYTHON:-python}   # training env from requirements-train.txt (mujoco 3.5, mujoco_warp, warp 1.12, torch CUDA)
cd rl_openarm
$PY env_openarm.py 4096                                      # benchmark
$PY train.py --envs 4096 --max_minutes 50 --out runs/rX     # current reward (v4/v5 coefficients); NOT tested from scratch: the delivered policy came from the staged runs r2→r5
P_OBST=0.75 $PY train.py --envs 4096 --max_minutes 15 --out runs/rY --resume runs/rX/modello.pt   # as in v5
$PY run_cpu.py eval --robot openarm --n 100 --json valutazione/a.json
$PY run_cpu.py eval --robot giorgio --n 100 --json valutazione/b.json      # add --no_buffer to remove Giorgio's front tray
MUJOCO_GL=egl $PY run_cpu.py video --robot openarm --seconds 10 --out openarm_standalone.mp4
MUJOCO_GL=egl $PY run_cpu.py video --robot giorgio --seconds 10 --out giorgio_transfer.mp4 --record giorgio_transfer.pkl
$PY grafico.py learning_curve_dark.png runs/r2/log.csv:450 runs/r3/log.csv runs/r4/log.csv runs/r5/log.csv
```
The reward coefficients were changed between phases (v2 → v3 → v4). `env_openarm.py` contains the last version. The
earlier values are noted in the code comments and in section 3.

## 7. Limits (honest list)

- **Simulation only.** The contact model, gripper pads and actuators are the official MJCF's idealised position servos.
  The real Damiao motors, CAN latency and gripper compliance have not been identified.
- **Privileged geometry.** The policy gets the cube *position*. In sim that comes from the simulator plus artificial
  noise, bias and latency, not from a rendered depth image run through Giorgio's actual segmentation code.
- **One object type** (a cube 4–6 cm). The policy has no knowledge of orientation or shape beyond what it learned for cubes.
- **Obstacles are invisible to the policy.** It learned to keep its links away from a randomized low obstacle near the
  base, but it does not *see* obstacles. Clutter or a different fixture would need training or an obstacle input.
- **Motion quality.** The policy is fast: the cube is above 10 cm about 0.7–1.2 s after the start. Grasps are
  sometimes not top-down, because the cube can be pinched at an angle. Occasionally (e.g. episode 2 of
  `giorgio_transfer.mp4`) it swings the cube higher, up to ~40 cm, before settling at 12 cm. On a real arm, speed and jerk
  limits and a smoother action filter should be added before deployment.
- The success threshold (10 cm, held 1 s) and the 6 s episode are our choice. Per-episode lift heights are in the JSONs.

## 8. Second skill: open a cabinet, drawer OR hinged door (added 2026-10-04)

**Why this task.** Grasp-and-lift a cube does not need learning: a scripted IK grasp solves it. We first tried
"open a drawer by its handle" and measured a scripted IK baseline on the same randomization **before** training:
it scored **95 %** (`valutazione/drawer_only_scripted_openarm.json`). So a drawer alone is not a good RL example either.
The task we kept is **"open the cabinet"**: the compartment is closed by a drawer, or by a door hinged on the left or
on the right. **The controller is not told which.** It gets only what a camera gives: the handle point, the
front-panel normal, and the handle type and size. A drawer must be pulled straight. A door must be pulled along an arc
whose centre is unknown, and the grasp has to survive the wrist rotation as the door turns. All of this happens
under friction, damping, springs and masses the controller cannot see.

Everything is in simulation (MuJoCo). The same pipeline is used as for the lift policy: PPO on mujoco_warp on the
standalone OpenArm 2.0, observations in the arm base frame, joint-position-target actions, randomization in the
standalone scene only. The same weights then run unchanged on Giorgio. There was no training on Giorgio.

**Scene.** A benchtop cabinet: a target compartment with a 30 x 18 cm front, a fixed drawer above it and a solid base
below it.
- Mechanisms: drawer 50 %, door hinged left 25 %, door hinged right 25 %.
- Handles:
  - drawer: horizontal bar (8–16 cm), vertical bar (8–11 cm) or knob (Ø 2.4–4.4 cm);
  - door: vertical bar or knob, near the free edge;
  - all handles: bar radius 5–12 mm, standoff 2.5–4.5 cm, friction 0.4–1.0.

**Randomization (standalone only).**
- Cabinet pose: front 0.44–0.56 m in front of the arm base, lateral −0.20…0.05 m, yaw ±20°, compartment 0.12–0.26 m
  above the table.
- Table: height and front edge as in the lift task.
- Drawer: Coulomb friction 1–15 N, damping 2–40 N·s/m, mass 0.5–4 kg, closing spring 0–40 N/m (50 % of episodes),
  initial opening 0–5 cm.
- Door: friction 0.1–1.5 N·m, damping 0.1–2 N·m·s/rad, mass 0.6–2 kg, closing spring 0–1 N·m/rad (50 % of episodes),
  initial opening 0–8°.
- Arm: kp/kv, damping and gravity compensation as in the lift task.
- A low obstacle in front of the base in 50 % of episodes.
- Perception: handle point bias ±7.5 mm per axis, noise 3 mm, latency 0–120 ms; panel-normal yaw error ±3°;
  handle-size error ±2 mm.
- Proprioception and actions: joint noise and latency, and the action applied one step late in 30 % of episodes,
  as in the lift task.

**Success:** the drawer is open ≥ 15 cm, or the door ≥ 60°, held for ≥ 0.48 s, within a 10 s episode, starting from
the arm retracted.

**Policy interface** (`policy_io_cabinet.py`):
- Observation (58 values):
  - joints (7 + 7 + 1), current targets (8);
  - grasp point and gripper axes from forward kinematics (9);
  - handle point "from vision" and handle − grasp point (6);
  - panel normal (3), handle bar axis (3), handle size (3);
  - handle displacement since the start of the episode (3);
  - last action (8).
- Action (8): the same as the lift policy, i.e. 7 joint-target increments plus the gripper command, at 25 Hz.
- Reward: dense reach and align terms, plus opening progress, minus a penalty for arm-link contacts and for
  action rate.

**Training** (`runs/c1`, `train.py --task cabinet`): PPO, 4,096 environments, 236 M control steps, 95 min on the
RTX 5070. The delivered weights are the ones at iteration 2,400 (`politica_openarm_cabinet.pt`).

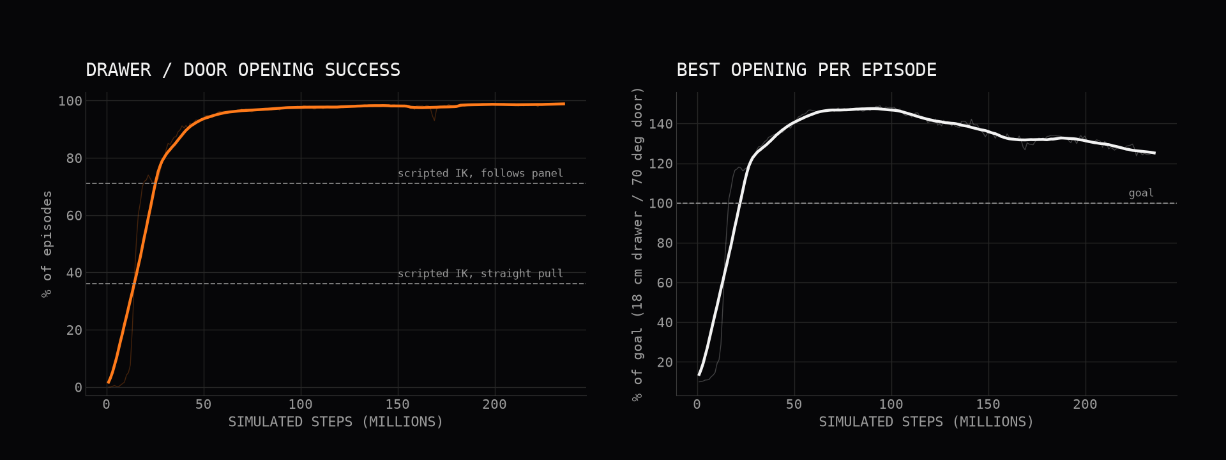
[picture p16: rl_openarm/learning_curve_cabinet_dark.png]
learning curve


The training curve shows the success of the *stochastic* training rollouts. The dashed lines are the two scripted
baselines (deterministic, 100 evaluation episodes).

### Results (100 randomized episodes each, noise + latency on; 95 % Wilson interval)

The scripted controllers and the policy were run on **the same 100 episodes** (same seed, same cabinets, same dynamics,
same noise).

| controller | standalone OpenArm 2.0 | Giorgio as built (front tray) | drawers | doors |
|---|---|---|---|---|
| untrained policy (50 ep.) | 0 % [0–7] | — | 0/18 | 0/32 |
| policy, early checkpoint (it. 100, 10 M steps) | 1 % [0.2–5.4] | — | 0/38 | 1/62 |
| **scripted IK, straight pull** | **36 %** [27.3–45.8] | **52 %** [42.3–61.5] | 36/38 · 52/53 | **0/62 · 0/47** |
| **scripted IK, follows the panel normal** | **71 %** [61.5–79.0] | **76 %** [66.8–83.3] | 36/38 · 52/53 | 35/62 · 24/47 |
| **RL policy (delivered)**, seed 0 | **96 %** [90.2–98.4] | **90 %** [82.6–94.5] | 38/38 · 53/53 | 58/62 · 37/47 |
| RL policy, seed 1 | 99 % [94.6–99.8] | 95 % [88.8–97.8] | 43/43 · 43/43 | 56/57 · 52/57 |
| RL policy, Giorgio with the front tray removed | — | 100 % [96.3–100] | 53/53 | 47/47 |

In the "drawers" and "doors" columns, "a · b" means standalone · Giorgio.

How the scripted baselines work (`run_cabinet.py`, `--controller scripted | scripted_follow`):
- They get **exactly the policy's inputs**: the same perception noise, bias and latency, and the same action
  interface and rate limit.
- They use damped least-squares IK on the arm model.
- On the standalone arm, which has no gravity compensation, they add gravity feed-forward as a set-point offset.
  Without it the uncompensated servos sag 2–3 cm and the grasp misses.
- The motion:
  1. pre-grasp 10 cm in front of the perceived handle;
  2. approach;
  3. close the gripper;
  4. pull.
- `scripted` pulls straight along the perceived normal: the classic drawer opener.
- `scripted_follow` re-reads the handle and the normal at every step and keeps pulling along the *current* normal, with
  the gripper re-oriented to it. This is a hand-written way to follow a door's arc.
- The grasp depth was tuned on nominal episodes, so these are tuned baselines, not strawmen.

What the numbers say:
- **Drawers:** scripted IK is as good as RL (95–98 % vs 100 %). This is why a drawer alone was not a good RL example.
- **Doors:**
  - the straight pull never reaches 60° (0/109; mean best 37° standalone, 43° on Giorgio). The gripper slips off the handle while the door
    turns.
  - following the panel normal helps (55 %), but the grasp is often lost as the wrist turns.
  - the policy opens 94–98 % of the doors on the standalone arm, and 79–91 % on Giorgio as built. It learned to keep contact and re-grasp, and to
    push the door past 60° once it is ajar. It needs no articulation model, no hinge estimate and no per-mechanism code.
- **What RL buys here:** one learned controller handles an unknown articulation, with contact, and with dynamics it
  cannot see. A scripted controller would need an articulation estimator and recovery logic written by hand.
  A better hand-written door opener is certainly possible. We did not write one.

**Transfer to Giorgio.**
- How it was run:
  - `scene_cabinet.build_giorgio()` stands the same cabinet on bench B, in front of the right arm (front 0.50 m,
    compartment 0.20 m above the bench);
  - `giorgio_model.py` is not modified;
  - the evaluation randomizes the placement: front 0.46–0.54 m, lateral −0.18…−0.05 m, yaw ±15°, compartment
    0.16–0.24 m above the bench;
  - it also randomizes the handle, the dynamics and the noise, exactly as on the standalone arm.
- No mapping fix was needed: same weights, observations in the arm base frame.
- **All Giorgio failures are doors that stop at 49–58°.**
  - Contact logging shows the door, or the gripper holding it, hitting Giorgio's front buffer tray (`amr` body) and
    the parked left arm.
  - The cause is the low cabinet placements: the door bottom is only 7–15 cm above the bench, and the tray stands
    ~10 cm tall.
  - With the tray removed the policy scores 100 %.
  - On the real robot, the cabinet should sit higher than the tray, or the left arm should be stowed lower. The same
    limitation is listed for the lift policy (section 3, item 6).
- Mean time to success: 2.0–2.4 s on both robots, including the 0.48 s hold. Mean best opening: ~22 cm for drawers,
  ~75° for doors.
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

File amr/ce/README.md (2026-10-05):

# Giorgio CE technical file (skeleton), design rev B - 2026-10-05

Rev B (owner decision 2026-10-05): **no waist yaw joint**. The superstructure is bolted to the fixed top deck (z 353 mm);
2 SICK nanoScan3 Pro I/O kept; every component chosen to be certifiable. All waist hazards, safety functions and tests
of rev A are removed and the IDs renumbered (SF1-SF17, H01-H44, TP-01-TP-22). SF1-SF16 are identical to
`../electrical/SAFETY_FUNCTIONS.md` rev B2 (TP-01b, TP-03a/b and TP-19b added in rev B2); SF17 (supervisory watchdog) is CE-only and not yet in the electrical package.
Safety controller rev B2: **Pilz PNOZmulti 2** (PNOZ m B0 + 2 × EF 4DI4DOR relay modules + ES ETH; C48 adds an EF 8DI4DO). Rev B2 applies the design changes of `../VERIFICATION.md` (93 items checked against official documents): no supplier answer is needed any more for the base.
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

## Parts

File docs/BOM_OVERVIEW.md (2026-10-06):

# Giorgio: bill of materials by subsystem

> Generated by `python scripts/bom_overview.py` from `amr/bom_amr.csv` (own AMR base rev B4) and `docs/bom.csv`
> (superstructure). **Component costs only**: EUR excluding VAT, quantity 1 (prototype), no labour and no margin.
> Status *documented* = a public price or a manufacturer/distributor document; *quote needed* = the price is an
> estimate or is behind a login and must be confirmed by a quote. Nothing has been bought yet.

## Totals

| Subsystem | Rows | Documented | Quote needed | Subtotal (EUR) |
|---|---:|---:|---:|---:|
| [Base AMR (structure, drives, castors, covers)](#base-amr-structure-drives-castors-covers) | 38 | 3 | 35 | 8,317 |
| [Safety](#safety) | 19 | 14 | 5 | 8,919 |
| [Power](#power) | 29 | 14 | 15 | 4,855 |
| [Dock](#dock) | 12 | 2 | 10 | 2,171 |
| [Arms & hands](#arms--hands) | 5 | 5 | 0 | 6,959 |
| [Vision & compute](#vision--compute) | 11 | 4 | 7 | 2,335 |
| [Structure & shells](#structure--shells) | 38 | 0 | 38 | 1,476 |
| [Coffee module](#coffee-module) | 19 | 3 | 16 | 1,025 |
| **Total, barista configuration** | **171** | **45** | **126** | **36,056** |

24,331 EUR (67%) of the total comes from documented prices; the rest is estimates waiting for quotes. Volume prices (at 10 and 50 units) for the base are in `amr/bom_amr.csv`.

Not included: options (certified-arm extras `arm_C48`, the larger NPB-1700 dock charger, ORCA Hand / AmazingHand instead of the OpenArm grippers, see [FEASIBILITY.md](../FEASIBILITY.md)), consumables (cups, capsules), labour and certification costs (see [amr/INDUSTRIALIZATION.md](../amr/INDUSTRIALIZATION.md)).

## Base AMR (structure, drives, castors, covers)

| Item | Part number | Qty | Unit (EUR) | Source | Status |
|---|---|---:|---:|---|---|
| D01 ez-Wheel SWD 125 (R/L) | EW2A-125HN04B (4:1 1-stage, brake, safety encoder… | 2 | 2,333.00 | [link](https://www.generationrobots.com/en/404239-swd-125-safety-wheel-drive.html) | documented |
| A02 Top deck = superstructure flange (z 353) | waterjet 15 mm 6082-T6 + CNC (column-foot M6 thro… | 1 | 400.00 | CNC shop Veneto / Weerg (Scorze VE) | estimate, quote needed |
| E28 Second safety I/O expansion SX2 for certified-arm safety I/O (C48 only) | Pilz PNOZ m EF 8DI4DO (772142) | 1 | 321.86 | [link](https://www.eibabo.de) | documented |
| A05 Tower roof 6 mm S355MC, no legs (castor bump-stop landing + scanner seat FR… | laser + bend 6 mm S355MC + machined scanner seat … | 4 | 60.00 | welding shop TV/PD | estimate, quote needed |
| C02 Castor carriage weldment (carriage plate + tongue + mast + shelf), FL/RR an… | laser 6/8 mm S355MC + weld + zinc flake | 4 | 60.00 | welding shop TV/PD | estimate, quote needed |
| C08 Linear guide block HIWIN MGN15H (Z0, standard seals), 2 per castor | HIWIN MGN15H | 8 | 30.00 | HIWIN Italia / distributor | quote needed |
| E43 SWD tunnel L/R (rev B4, F3): 2 mm 5754 hood + end cap + baffle, EPDM lip se… | laser + bend 2 mm 5754, riveted; EPDM lip + brush… | 2 | 70.00 | laser/sheet-metal shop TV/PD (quote) | estimate, quote needed |
| A01 Floor pan | laser 5 mm S355MC + PEM M6 + powder coat | 1 | 130.00 | laser/sheet-metal shop TV/PD (quote) / LaserBoost | estimate, quote needed |
| C01 Swivel castor Blickle L-ALST 80K (ID 754464): D80 x 30 Softhane 75 ShA, 200… | Blickle L-ALST 80K (754464): 200 kg at 4 km/h; re… | 4 | 30.00 | Blickle Italia | quote needed |
| A03 Spine R (DIN bay, safety) | waterjet 6 mm 6082-T6 + tapped M5/M6 rows | 1 | 110.00 | CNC shop Veneto | estimate, quote needed |
| A03 Spine L (DIN bay, power) | waterjet 6 mm 6082-T6 + tapped M5/M6 rows | 1 | 110.00 | CNC shop Veneto | estimate, quote needed |
| K01 Cover front | laser + bend 2 mm 5754 + powder RAL 9016 + tricol… | 1 | 110.00 | sheet-metal + powder coater TV | estimate, quote needed |
| K02 Cover rear (fan exhaust + rear panel devices) | laser + bend 2 mm 5754 + powder RAL 9016 | 1 | 110.00 | sheet-metal + powder coater TV | estimate, quote needed |
| K03 Cover left (fan intake) | laser + bend 2 mm 5754 + powder RAL 9016 | 1 | 110.00 | sheet-metal + powder coater TV | estimate, quote needed |
| K04 Cover right (fan intake) | laser + bend 2 mm 5754 + powder RAL 9016 | 1 | 110.00 | sheet-metal + powder coater TV | estimate, quote needed |
| C07 Linear guide rail HIWIN MGN15R, L 190 (15 + 4 x 40 + 15) | HIWIN MGN15R L190 | 4 | 25.00 | HIWIN Italia / distributor | quote needed |
| E40 Fan 60x60x25 24 V IP54 + filter grille, side bays (Lin/Lout/Rin/Rout) | San Ace 9WPA0624S4001 (60x60x25, 24 V, 59.4 m3/h,… | 4 | 25.00 | Sanyo Denki / distributors | quote needed |
| C04 Compression spring Gutekunst D-313J-02 (d 3.6, De 31.6, L0 53.9, R 14.172 N… | Gutekunst D-313J-02 | 8 | 12.37 | Gutekunst Federn (federnshop.com) | documented |
| Z01 Fasteners, PEM, inserts, ties, glands, labels, CE nameplate | ISO 4762/7380, PEM, Lapp Skintop | 1 | 95.00 | Wuerth Italia / Bossard | estimate, quote needed |
| B03 Battery strap (F0/F1/R0/R1) | laser 3 mm 5754 + 2 bends | 4 | 20.00 | Weerg (5754 cut) + local bending | estimate, quote needed |
| A04 Post 30x30x3 (FL/FR/RL at (±360, ±106); RR replaced by bracket A07) | tube EN 755-2 6082, cut + drill | 3 | 25.00 | sheet-metal/CNC shop Veneto | estimate, quote needed |
| D02 SWD cheek plates (2 per drive, on the gearbox fixing points M6 50 x 100; re… | waterjet 8 mm 6082-T6 + drill/tap | 4 | 18.00 | Weerg / CNC shop | estimate, quote needed |
| A09 Deck doubler under the column foot (rev B4, G-19), x -160..34, /y/ <= 131 | waterjet 15 mm 6082-T6, 8 x M6 through holes on t… | 1 | 60.00 | CNC shop Veneto / Weerg (Scorze VE) | estimate, quote needed |
| E44 Tunnel fan L/R on the SWD tunnels (rev B4, F3) | San Ace 9WPA0624S4001 (60x60x25, 24 V, IP68) | 2 | 25.00 | Sanyo Denki / distributors | quote needed |
| C05 Spring bracket (8 mm S355MC, bent, vertical M6 slots for the preload settin… | laser + bend 8 mm S355MC + zinc flake | 4 | 12.00 | sheet-metal shop TV/PD | estimate, quote needed |
| K06 Jetson cover on the rear deck (CAD K06; CERTAINTY M9) | laser + bend 2 mm 5754, slotted louvres, powder R… | 1 | 45.00 | laser/sheet-metal shop TV/PD (quote) | estimate, quote needed |
| K3 Arm-feed precharge K3 (Finder 22.32 + Vishay RH-50 12R; C48 only; rev B4 G-1… | Finder 22.32.0.024.4340 + Vishay Dale RH050 12R0 | 1 | 45.00 | Finder / RS | estimate, quote needed |
| A07 Corner bracket RR (corner rail for U8 + roof + deck corner; replaces the RR… | waterjet 6 mm 6082-T6 + tap M5 | 1 | 40.00 | CNC shop Veneto / Weerg | estimate, quote needed |
| K05 Rubber edge EPDM 22 mm | Angst+Pfister APSOseal 1025058803 EPDM profile 25… | 1 | 40.00 | Angst+Pfister (apsoparts.com) | quote needed |
| A06 Corner bracket FL (spine extension: corner rail for U7 + roof support) | waterjet 6 mm 6082-T6 + tap M5 | 1 | 35.00 | CNC shop Veneto / Weerg | estimate, quote needed |
| E53 Deck cable-entry frame IP54 (base -> superstructure) | icotek KEL-DPZ class | 1 | 35.00 | icotek / distributor | estimate, quote needed |
| B02 Battery pad EPDM 3 mm (F/R) | die-cut EPDM 3 mm | 2 | 15.00 | rubber die-cutter Veneto | estimate, quote needed |
| E42 Fan 40x40x20 24 V (IP54 class) + finger guard, centre-bay supply in the spi… | San Ace 9WPA0424H6001 (40x40x20, 24 V, 14.4 m3/h,… | 2 | 15.00 | Sanyo Denki / distributors | quote needed |
| A08 Rail bracket RL (left HIGH rail extension above the RL scanner) | waterjet 6 mm 6082-T6 + tap M5 | 1 | 25.00 | CNC shop Veneto / Weerg | estimate, quote needed |
| A10 Rail bracket FR (right HIGH rail extension to x 298: SR3, CAN1; rev B4) | waterjet 6 mm 6082-T6 + tap M5 | 1 | 25.00 | laser/sheet-metal shop TV/PD (quote) | estimate, quote needed |
| C06 Droop stop: rubber buffer Ganter GN 351-20-15-M6-SS-55 + 4 mm angle (angle … | Ganter GN 351-20-15-M6-SS-55 (NR 55 Shore, 480 N … | 4 | 4.00 | Ganter / norelem dealers | quote needed |
| C09 Castor fasteners: 16 x M8x16 ISO 10642 10.9, 20 x M3x10, 32 x M3x8, 16 x M6… | ISO 10642 / ISO 4762 | 1 | 10.00 | fastener distributor | estimate, quote needed |
| C03 PU bump pad 30 x 30 x 3, 90 ShA, bonded | Angst+Pfister APSOplast PUR D15 90A sheet 3 mm (0… | 4 | 1.00 | Angst+Pfister | quote needed |
| **Subtotal** | | | **8,317** | | |

## Safety

| Item | Part number | Qty | Unit (EUR) | Source | Status |
|---|---|---:|---:|---|---|
| S01 SICK nanoScan3 Pro I/O (0/1) | NANS3-CAAZ30AN1 (1100334) | 2 | 2,394.95 | [link](https://vb-steuerungstechnik.de/Sick-NANS3-CAAZ30AN1-/-1100334-/-nanoScan3-Pro-/-Safety-Laser-Scanner_1) | documented |
| E21 Safety controller base unit SC0 Pilz PNOZ m B0 (20 safe in, 4 safe SC out, … | Pilz PNOZ m B0 (772100) | 1 | 784.12 | [link](https://www.eibabo.de/pilz/sicherheitssteuerung-pnoz-m-b0-eb16105018) | documented |
| S02 nanoScan3 system plug NANSX-AAACZZZZ1 (2105107), 300 mm, supply + I/O | NANSX-AAACZZZZ1 (scanner ships without plug, SICK… | 2 | 265.73 | eibabo.de / SICK Italia | documented |
| SE1 Handheld pendant, 3-position enabling switch + jog (manual mode) | Euchner ZSA2B4G02CC2322 (169871): EN 60947-5-8, 2… | 1 | 500.00 | Euchner Italia / distributors | quote needed |
| E2H Safety relay expansion SR1 Pilz PNOZ m EF 4DI4DOR (SWD STO_1/2 + INSafe_1/2… | Pilz PNOZ m EF 4DI4DOR (772143) | 1 | 379.72 | Pilz Italia / eibabo.de | documented |
| E2I Safety relay expansion SR2 Pilz PNOZ m EF 4DI4DOR (scanner CI1-CI4 relay co… | Pilz PNOZ m EF 4DI4DOR (772143) | 1 | 379.72 | Pilz Italia / eibabo.de | documented |
| E2M Safety relay expansion SR3 Pilz PNOZ m EF 4DI4DOR (SWD INSafe_3/4 = SLS[2] … | Pilz PNOZ m EF 4DI4DOR (772143) | 1 | 379.72 | [link](https://www.eibabo.de) | documented |
| E20 Safety controller Ethernet/Modbus TCP module SC1 Pilz PNOZ m ES ETH | Pilz PNOZ m ES ETH (772130) | 1 | 268.89 | [link](https://www.eibabo.de) | documented |
| E2C Arm-bus safety contactor K1 (mirror contact) | Siemens 3RT2026-1BB40 | 1 | 202.10 | Siemens / RS | documented |
| E2D Arm-bus safety contactor K2 (mirror contact) | Siemens 3RT2026-1BB40 | 1 | 202.10 | Siemens / RS | documented |
| HL1 Signal tower + buzzer 24 V (ISO 3691-4 warning) | Patlite WME-302DFB-RYG (24 V DC, 3 tiers + buzzer… | 1 | 120.00 | Werma / Patlite distributor | quote needed |
| SCT Pilz plug-in spring terminal sets for B0 + EF | Pilz 751008 (B0) + 3 x 751004 (SR1-SR3) | 1 | 115.23 | Pilz Italia | documented |
| E02 E-stop Siemens SIRIUS ACT 3SU1 (R/L): mushroom twist-release + holder + 2x … | Siemens 3SU1050-1HB20-0AA0 (40 mm, EN ISO 13850, … | 2 | 33.56 | Siemens Italia / RS / DigiKey.it | documented |
| E59 Jetson GPIO -> HL1 signal tower interface JR1: 2 solid-state modules (rev B… | 2x Phoenix EMG 17-OV-TTL/24DC/2 (2943259): TTL in… | 1 | 60.00 | Phoenix Contact Italia | estimate, quote needed |
| E41 Key selector AUTO/MANUAL/SERVICE (rear panel) | Eaton M22-WRS3 (216900) + 2x M22-K10 (216376) (Ea… | 1 | 52.64 | Eaton Italia / DigiKey.it | documented |
| RB1-10 Bleed resistors Vishay PR01 2.2 kOhm 1 W in Phoenix double-level compone… | Vishay PR01 2.2 kOhm 1 W + component terminal | 10 | 4.00 | Phoenix Contact Italia / RS | estimate, quote needed |
| E41 M12 socket for the enabling pendant (rear panel), 5-pole A-coded | binder 76 0632 1011 00005-0200 (M12-A female, 5 p… | 1 | 25.00 | binder / distributors | quote needed |
| E41 Reset pushbutton blue illuminated (rear panel) | Eaton M22-DL-B (216931) + M22-K10 (216376) (Eaton… | 1 | 12.83 | Eaton Italia / DigiKey.it | documented |
| E2J Interposing relay KI4 for the K4 coil (Phoenix PLC-RSC-24DC/21, 6.2 mm) | Phoenix PLC-RSC-24DC/21 (2966171), input 9 mA | 1 | 8.69 | Phoenix Contact Italia | documented |
| **Subtotal** | | | **8,919** | | |

## Power

| Item | Part number | Qty | Unit (EUR) | Source | Status |
|---|---|---:|---:|---|---|
| B01 Discover AES PRO DLP-GC2-48V (F/R), lying on its side, >= 50 mm free at the… | DLP-GC2-48V LFP 51.2 V 30 Ah | 2 | 930.00 | Discover EU distributor (to identify) | estimate, quote needed |
| H01..H10 Harnesses H01-H10 (battery, B48, traction, dock, scanner M12, E-stops,… | Lapp / H07Z-K cable + SICK M12 cordsets | 1 | 560.00 | harness subcontractor Veneto | estimate, quote needed |
| G01 Discover LYNK II gateway G01 (120 x 135 x 44 mm on bracket E38b, right bay;… | 950-0025 | 1 | 350.00 | Discover EU distributor | estimate, quote needed |
| E16 Shunt regulator T24 27 V R1a/R1b (deck underside above the rear pack) | maxon DSR 50/5 (309687) | 2 | 145.15 | [link](https://www.maxongroup.com/maxon/view/product/309687) | documented |
| E13 Traction DC-DC U1 | Mean Well DDR-480C-24 | 1 | 165.00 | [link](https://www.digikey.it/it/products/result?keywords=DDR-480C-24) | documented |
| E14 Traction DC-DC U2 | Mean Well DDR-480C-24 | 1 | 165.00 | [link](https://www.digikey.it/it/products/result?keywords=DDR-480C-24) | documented |
| E03 Albright ED250B-L key-lockable service disconnect (blowouts; no-load isolat… | ED250B-L | 1 | 150.00 | Albright UK / forklift spares | estimate, quote needed |
| E2K 48 V application low-voltage cut-off K0V: Carlo Gavazzi DUB01CD48500V (50 V… | Carlo Gavazzi DUB01CD48500V | 1 | 144.90 | Carlo Gavazzi Italia / DigiKey.it | documented |
| E15 Auxiliary 24 V DC-DC U4 (S24) | Mean Well DDR-240C-24 | 1 | 134.08 | Melchioni / Gigatek / DigiKey.it | documented |
| E18 Branch fuse holders 10x38 gPV + links + comb (x6: F1-F4, F5L, F5R) | Mersen 10x38 DC holder CUS101HEL x6 + HP10M gPV: … | 1 | 132.90 | Mersen / DigiKey.it | documented |
| E11 Main contactor K0 Albright SW80B...A (blowouts B, aux A, continuously rated… | SW80B...A 24 V DC continuous coil | 1 | 130.00 | Albright UK / forklift spares | estimate, quote needed |
| E27 S24 fuse terminals + safety terminals + bridges | Phoenix PT 2,5 / PT 4 / PT 4-HESI + FBS | 1 | 90.00 | Phoenix Contact Italia / DigiKey.it | estimate, quote needed |
| E2F AUX48 branch fuses WF1 6 A / WF2 12 A / WF3 2 A + FJ 4 A on 12 V (CAD E2L) … | Mersen CUS101HEL x4 + HP10M6 / HP10M12 / HP10M2 /… | 1 | 78.60 | Mersen / DigiKey.it | documented |
| E2G Jetson 12 V DC-DC U5 (right LOW rail rear) | Mean Well DDR-120C-12 | 1 | 63.66 | Melchioni / Gigatek / DigiKey.it | documented |
| E30 ORing module T24 (centre bay LOW right) | Mean Well DRDN40-24 | 1 | 55.59 | Melchioni / DigiKey.it | documented |
| E34 Charge-path ideal diode U8 (RR corner rail) | Mean Well DRDN40-48 | 1 | 54.45 | Melchioni / DigiKey.it | documented |
| E58 Head 5 V DC-DC U6 (left MID rail above the SWD; 52.5 mm wide, vertical) | Mean Well DDR-60L-5 | 1 | 47.34 | Melchioni / DigiKey.it | documented |
| E12 Precharge relay K0P + resistor 47R | Finder 22.32.0.024.4340 + Vishay Dale RH-50 (RH05… | 1 | 45.00 | Finder (Almese TO) / RS | estimate, quote needed |
| E5A Deck-interface terminals XC (ES3, PSEN, HL1, coffee 24 V, head 5 V), right … | Phoenix PT 1.5 / PT 4 | 1 | 45.00 | Phoenix Contact Italia | estimate, quote needed |
| E10 Main fuse F0 Siemens 3NA3830 100 A gG size NH000 (250 V DC, 25 kA DC) in an… | Siemens 3NA3830 + 3NH3030 | 1 | 40.00 | Siemens / RS / DigiKey.it | estimate, quote needed |
| D0 Freewheel diode on the K0 SW80 coil + Siemens diode/Zener suppressors on K1/… | Vishay 1N5408 (3 A, 1000 V, IFSM 200 A) across th… | 1 | 40.00 | Phoenix / Siemens | estimate, quote needed |
| E31 SWD feed fuses F8L/F8R 20 A gPV (holder + link) x2 | Mersen CUS101HEL + HP10M20 x2 | 1 | 39.30 | Mersen / DigiKey.it | documented |
| E19 0 V distribution block + chassis strap | Weidmueller WPD 100 2X25/6X10 GY (1561910000), 10… | 1 | 36.02 | Weidmueller Italia | documented |
| E17 K0 on-delay timer K0T 0.6 s (hard-wired K0 sequence) | Finder 80.01.0.240.0000 | 1 | 35.00 | Finder (Almese TO) / RS | estimate, quote needed |
| E0x DIN rails TS35 side bays (L: lower F/R, MID, upper F/R, corner FL; R: lower… | Phoenix NS 35/7,5 (EN 60715), cut to length | 1 | 30.00 | Phoenix / Weidmueller Italia | estimate, quote needed |
| E38b LYNK II bracket (2 mm 5754, hung from the deck, against the right side cov… | laser + bend 2 mm 5754 | 1 | 25.00 | sheet-metal shop TV/PD | estimate, quote needed |
| E32 T24 power terminals (2) | Phoenix PT 16-N (3212138) feed-through 16 mm2, 76… | 1 | 20.00 | Phoenix Contact Italia | estimate, quote needed |
| E33 Charge-path fuse F7 (holder + link) | Mersen CUS101HEL + HP10M32 | 1 | 19.65 | Mersen / DigiKey.it | documented |
| E0C Centre-bay DIN rails TS35 E0C_L / E0C_R at z 213 (spine inner faces), 154 m… | EN 60715, 154 mm | 2 | 4.00 | Phoenix / Weidmueller Italia | estimate, quote needed |
| **Subtotal** | | | **4,855** | | |

## Dock

| Item | Part number | Qty | Unit (EUR) | Source | Status |
|---|---|---:|---:|---|---|
| X01 Dock frame | laser + bend 4 mm S355MC welded + powder | 1 | 445.00 | sheet-metal shop TV/PD | estimate, quote needed |
| E01 Roboteq RoboPad extendable collector RPCOL90-100 (60 A continuous; passive,… | RPCOL90-100 | 1 | 400.00 | Roboteq/Nidec direct | estimate, quote needed |
| X05 Dock controller Finder OPTA (Wi-Fi/Ethernet handshake) + DC contactor Albri… | Finder OPTA 8A.04.9.024.8320 + Albright SW80B...A… | 1 | 396.00 | in-house assembly | estimate, quote needed |
| X02 Roboteq RoboPad base | RPBAS90-100 | 1 | 300.00 | Roboteq/Nidec direct | estimate, quote needed |
| X04 Charger Mean Well NPB-750-48 (11.3 A, EMC Class B, DIP flooded 56.8/53.6 V) | NPB-750-48 | 1 | 171.72 | Melchioni / Gigatek / DigiKey.it | documented |
| X09 Dock over-voltage relay XD3: Carlo Gavazzi DUB01CD48500V (200 V range, over… | Carlo Gavazzi DUB01CD48500V | 1 | 144.90 | Carlo Gavazzi Italia / DigiKey.it | documented |
| X07 Dock cover | bend 2 mm 5754 + powder | 1 | 120.00 | sheet-metal shop TV/PD | estimate, quote needed |
| X03 Pad mount | bend 3 mm S355MC + powder | 1 | 80.00 | sheet-metal shop TV/PD | estimate, quote needed |
| X08 Dock harness (mains cable, switch, glands) | Lapp OELFLEX CLASSIC 110 3G1.5 (1119303) + Schurt… | 1 | 60.00 | Lapp / Schurter | estimate, quote needed |
| X06 AprilTag + retro-reflective plate | UV print on aluminium + 3M tape | 1 | 30.00 | local printer | estimate, quote needed |
| E37 Dock signature relay KS (PNOZ standard output) | Finder 38.51.7.024.0050 | 1 | 15.00 | Finder / RS | estimate, quote needed |
| E35 Dock signature resistor 10 kOhm in component terminal | Phoenix component terminal block + Vishay PR02 10… | 1 | 8.00 | Phoenix Contact Italia | estimate, quote needed |
| **Subtotal** | | | **2,171** | | |

## Arms & hands

| Item | Part number | Qty | Unit (EUR) | Source | Status |
|---|---|---:|---:|---|---|
| Enactic OpenArm 2.0 bimanual (2 arms, torso body_link0, 2 grippers, wrist camer… | OpenArm 2.0 bimanual | 1 | 5,950.00 | [link](https://docs.openarm.dev/purchase) | documented |
| E52 Arm-bus ORing + 27 V clamp: 2x DRDN40-24 (CAD E52_L/R) + 2x maxon DSR 50/5 … | DRDN40-24 x2 + DSR 50/5 x2 | 1 | 401.48 | Melchioni / maxon | documented |
| E50 Arm 24 V DC-DC R/L (moved from waist plate; OpenArm variant only) | Mean Well DDR-480C-24 | 2 | 165.00 | [link](https://www.digikey.it/it/products/result?keywords=DDR-480C-24) | documented |
| SP1 Arm-on-rest sensors Pilz PSEN cs3.1 + actuator cs3.11 (L/R, each on its own… | Pilz PSEN cs3.1 M12/8-0.15m (541009) + actuator P… | 2 | 119.34 | Pilz Italia / eibabo.de | documented |
| E57 Arm feed fuses FAL/FAR 25 A gPV (holder + link) x2, right MID rail (OpenArm… | Mersen CUS101HEL + HP10M25 x2 | 1 | 39.30 | Mersen / DigiKey.it | documented |
| **Subtotal** | | | **6,959** | | |

## Vision & compute

| Item | Part number | Qty | Unit (EUR) | Source | Status |
|---|---|---:|---:|---|---|
| E51 Jetson Orin NX 16 GB box: Seeed reComputer J4012 (superstructure compute, o… | Seeed reComputer J4012 (110110145), 9-19 V input,… | 1 | 1,287.00 | Seeed Studio | documented |
| Orbbec Gemini 336L stereo depth camera | Gemini 336L | 1 | 340.00 | [link](https://store.orbbec.com/products/gemini-336l) | documented |
| E36 CAN-Ethernet gateway (traction + energy CAN), 22.5 x 99 x 114.5 mm, right H… | PEAK PCAN-Ethernet Gateway DR (IPEH-004010) | 1 | 294.00 | PEAK-System / distributor | documented |
| E25 Ethernet switch 8 port DIN | Phoenix FL SWITCH 1008N (1085256), 9-32 V DC, 22.… | 1 | 141.86 | Phoenix Contact Italia | documented |
| USB UVC fisheye camera ~180 deg 1080p (front + back), replaces Insta360 X4 | Arducam/e-con class | 2 | 50.00 | estimate (FEASIBILITY.md section 3.7 option A) | estimate, quote needed |
| Powered USB 3 hub, 7 port, 12 V input |  | 1 | 60.00 | estimate (FEASIBILITY.md section 6: 9-11 USB devi… | estimate, quote needed |
| USB CAN-FD adapter, SocketCAN gs_usb class (CANable 2.0 / candleLight FD) for t… | CANable 2.0 class | 1 | 40.00 | estimate; mainline Linux gs_usb driver | estimate, quote needed |
| ESP32-S3 HUB75 driver board (Matrix Portal S3 class) |  | 1 | 25.00 | estimate (FEASIBILITY.md section 3.10) | estimate, quote needed |
| HUB75 32x16 P4 RGB LED panel |  | 1 | 20.00 | estimate | estimate, quote needed |
| LED strips / mustache diffuser LEDs |  | 1 | 15.00 | estimate (README v7 line 40 EUR incl. eyes) | estimate, quote needed |
| GC9A01 1.28 in round displays (eyes) |  | 2 | 6.00 | README v3/v7 (5-10 EUR each) | estimate, quote needed |
| **Subtotal** | | | **2,335** | | |

## Structure & shells

| Item | Part number | Qty | Unit (EUR) | Source | Status |
|---|---|---:|---:|---|---|
| P02_column_to_torso_bracket (EN AW-6082-T6, 1.823 kg) |  | 1 | 216.00 | estimate: process cost model | estimate, shop quote needed |
| P29_column_foot (EN AW-6082-T6, 1.248 kg) |  | 1 | 205.00 | estimate: process cost model | estimate, shop quote needed |
| SH03_waist_cover (PA12 (SLS/MJF), 0.522 kg) |  | 1 | 155.00 | estimate: process cost model | estimate, shop quote needed |
| P20_tray_half_L (PA12 (SLS/MJF), 0.888 kg) |  | 1 | 143.00 | estimate: process cost model | estimate, shop quote needed |
| P20_tray_half_R (PA12 (SLS/MJF), 0.888 kg) |  | 1 | 143.00 | estimate: process cost model | estimate, shop quote needed |
| SH04b_torso_shell_rear (PA12 (SLS/MJF), 0.274 kg) |  | 1 | 100.00 | estimate: process cost model | estimate, shop quote needed |
| SH04a_torso_shell_front (PA12 (SLS/MJF), 0.251 kg) |  | 1 | 95.00 | estimate: process cost model | estimate, shop quote needed |
| SH05_head_shell (PA12 (SLS/MJF), 0.149 kg) |  | 1 | 73.00 | estimate: process cost model | estimate, shop quote needed |
| item Profil 8 80x80 leicht 0.0.265.80 cut 370 mm + machining | item 0.0.265.80 | 1 | 60.00 | estimate (item price ~25 EUR/m + cut/drill/tap) | estimate, quote needed |
| SH02_column_cover_fixed (PA12 (SLS/MJF), 0.061 kg) |  | 1 | 53.00 | estimate: process cost model | estimate, shop quote needed |
| Minimum-pack overhead, threadlocker, cable ties, glands |  | 1 | 40.00 | estimate | estimate, quote needed |
| P19_tray_carrier (EN AW-5754-H22, 0.429 kg) |  | 1 | 35.00 | estimate: process cost model | estimate, shop quote needed |
| P16_head_neck_plate (EN AW-5754-H22, 0.100 kg) |  | 1 | 24.00 | estimate: process cost model | estimate, shop quote needed |
| P18_gemini_bracket (EN AW-5754-H22, 0.077 kg) |  | 1 | 23.00 | estimate: process cost model | estimate, shop quote needed |
| P27_torso_shell_bracket_front (EN AW-5754-H22, 0.046 kg) |  | 1 | 22.00 | estimate: process cost model | estimate, shop quote needed |
| P28_torso_shell_bracket_rear (EN AW-5754-H22, 0.047 kg) |  | 1 | 22.00 | estimate: process cost model | estimate, shop quote needed |
| T-slot nut slot 6 M5 (ASSUMED type) |  | 16 | 0.90 | estimate | estimate, quote needed |
| ISO 7379 shoulder screw D8x8 M6 (locating pin; head relieved in the tray) |  | 4 | 3.00 | estimate | estimate, quote needed |
| Kerb Konus 860 M4 threaded inserts |  | 9 | 1.20 | estimate | estimate, quote needed |
| T-slot nut slot 8 M6 (ASSUMED Misumi post) |  | 10 | 1.00 | estimate | estimate, quote needed |
| ISO 4762 M5x10 8.8 |  | 28 | 0.13 | estimate (A2/8.8 catalogue price) | estimate, quote needed |
| ISO 4762 M6x10 8.8 |  | 16 | 0.16 | estimate (A2/8.8 catalogue price) | estimate, quote needed |
| ISO 7089 washers (all sizes) |  | 75 | 0.03 | estimate | estimate, quote needed |
| ISO 10642 M5x16 8.8 |  | 16 | 0.13 | estimate (A2/8.8 catalogue price) | estimate, quote needed |
| DIN 7984 M12x30 8.8 |  | 2 | 0.90 | estimate (A2/8.8 catalogue price) | estimate, quote needed |
| ISO 4762 M6x16 8.8 |  | 8 | 0.16 | estimate (A2/8.8 catalogue price) | estimate, quote needed |
| ISO 4762 M6x30 8.8 |  | 8 | 0.16 | estimate (A2/8.8 catalogue price) | estimate, quote needed |
| ISO 4762 M4x16 8.8 |  | 10 | 0.10 | estimate (A2/8.8 catalogue price) | estimate, quote needed |
| ISO 4762 M4x8 8.8 |  | 7 | 0.10 | estimate (A2/8.8 catalogue price) | estimate, quote needed |
| ISO 4762 M4x12 8.8 |  | 6 | 0.10 | estimate (A2/8.8 catalogue price) | estimate, quote needed |
| ISO 4762 M5x12 8.8 |  | 4 | 0.13 | estimate (A2/8.8 catalogue price) | estimate, quote needed |
| ISO 7380 M5x16 8.8 |  | 4 | 0.13 | estimate (A2/8.8 catalogue price) | estimate, quote needed |
| ISO 4762 M4x18 8.8 |  | 4 | 0.10 | estimate (A2/8.8 catalogue price) | estimate, quote needed |
| ISO 4762 M3x8 8.8 |  | 4 | 0.08 | estimate (A2/8.8 catalogue price) | estimate, quote needed |
| ISO 4762 M3x16 8.8 |  | 3 | 0.08 | estimate (A2/8.8 catalogue price) | estimate, quote needed |
| ISO 4762 M4x10 8.8 |  | 2 | 0.10 | estimate (A2/8.8 catalogue price) | estimate, quote needed |
| ISO 4762 M4x6 8.8 |  | 2 | 0.10 | estimate (A2/8.8 catalogue price) | estimate, quote needed |
| ISO 4032 M5 nuts |  | 4 | 0.05 | estimate | estimate, quote needed |
| **Subtotal** | | | **1,476** | | |

## Coffee module

| Item | Part number | Qty | Unit (EUR) | Source | Status |
|---|---|---:|---:|---|---|
| SH06_coffee_housing (PA12 (SLS/MJF), 0.641 kg) |  | 1 | 181.00 | estimate: process cost model | estimate, shop quote needed |
| E54 Coffee 24 V DC-DC U7 (FL corner rail; barista only) | Mean Well DDR-480C-24 | 1 | 165.00 | Melchioni / Gigatek / DigiKey.it | documented |
| 24 V DC capsule machine, Nespresso-compatible, 300 W (truck type) |  | 1 | 120.00 | [link](https://www.truckstyler-shop.de/Suitable-for-Nespresso-Truck-24V-coffee-capsule-machine?slotID=2) | documented |
| P21_coffee_shelf (EN AW-6082-T6, 1.066 kg) |  | 1 | 112.00 | estimate: process cost model | estimate, shop quote needed |
| Actuonix P16-150-64-12-P linear actuator (cup shuttle) | P16-150-64-12-P | 1 | 95.00 | estimate (Actuonix list ~USD 100) | estimate, quote needed |
| HIWIN MGN12 rail L=190 + MGN12H carriage | MGN12-190 + MGN12H | 1 | 45.00 | estimate | estimate, quote needed |
| E55 Coffee power relay K4 (via interposing relay KI4 on a PNOZ auxiliary output… | Finder 22.32.0.024.4340 | 1 | 40.00 | Finder / RS | estimate, quote needed |
| P26_cup_stack_holder (PA12 (SLS/MJF), 0.172 kg) |  | 1 | 36.00 | estimate: process cost model | estimate, shop quote needed |
| Coffee MCU: RP2040 + DRV8871 H-bridge + relay + cup-present sensor + 12 V buck |  | 1 | 30.00 | FEASIBILITY.md section 5 (+30) | estimate, quote needed |
| P22_coffee_upright_0 (EN AW-5754-H22, 0.231 kg) |  | 1 | 28.00 | estimate: process cost model | estimate, shop quote needed |
| P22_coffee_upright_1 (EN AW-5754-H22, 0.231 kg) |  | 1 | 28.00 | estimate: process cost model | estimate, shop quote needed |
| P30_backpack_eplate (EN AW-5754-H22, 0.184 kg) |  | 1 | 26.00 | estimate: process cost model | estimate, shop quote needed |
| P24_shuttle_cup_carrier (PA12 (SLS/MJF), 0.089 kg) |  | 1 | 23.00 | estimate: process cost model | estimate, shop quote needed |
| P23_shuttle_rail_riser (EN AW-6082-T6, 0.041 kg) |  | 1 | 20.00 | estimate: process cost model | estimate, shop quote needed |
| P25_actuator_rear_bracket (EN AW-5754-H22, 0.011 kg) |  | 1 | 20.00 | estimate: process cost model | estimate, shop quote needed |
| E56 Coffee fuse FCF 15 A gPV (holder + link; barista only) | Mersen CUS101HEL + HP10M15 | 1 | 19.65 | Mersen / DigiKey.it | documented |
| P31_backpack_standoff_0 (EN AW-6082-T6, 0.019 kg) |  | 1 | 12.00 | estimate: process cost model | estimate, shop quote needed |
| P31_backpack_standoff_1 (EN AW-6082-T6, 0.019 kg) |  | 1 | 12.00 | estimate: process cost model | estimate, shop quote needed |
| P31_backpack_standoff_2 (EN AW-6082-T6, 0.019 kg) |  | 1 | 12.00 | estimate: process cost model | estimate, shop quote needed |
| **Subtotal** | | | **1,025** | | |
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

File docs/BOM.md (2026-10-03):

# Giorgio - consolidated bill of materials

Generated by `electrical/make_bom.py netlist_rangermini.yaml base_choice_rangermini.yaml` on the current CAD export, netlist rev E4.0 (2026-10-03) Ranger Mini 3.0, own 15s 30 Ah pack charged from the base accessory output and base choice **AgileX Ranger Mini 3.0 + own 48 V 15s 30 Ah pack charged from the base port; AgileX charging kit (NAVIS)**. Machine-readable copy: `docs/bom.csv`. EUR excluding VAT, prototype quantity 1. Prices marked *estimate* are not quotes.

## Totals

| | EUR |
|---|---|
| **Sum of parts, barista configuration (default)** - no margin, no labour - **excluding** AgileX charging kit / auto-charging pile + NAVIS module (prices not published) | **31,869** |
| of which barista-only items (coffee backpack, coffee DC-DC/relay/fuse, backpack structure) | 904 |
| Optional: assembly and test labour, 35 h x 50 EUR/h (README v7) | 1,750 |

## Cost-down options (owner: "the whole thing must cost little"; safety functions stay PL d)

The **standard** configuration above already uses the cheapest parts that pass every check in `CHECKS_*.md`:

- Jetson Orin NX 16 GB (100 TOPS class) instead of AGX Orin 64 GB: it runs Gemini 336L depth + 2 fisheye + 2 wrist cams, YOLO-class detection + grasp pose (TensorRT INT8), one ACT/diffusion policy at 10-30 Hz and ASR/TTS; the LLM agent runs in the cloud. Saves ~EUR 2,250 and ~1 kg; 12 V rail drops to a DDR-60L-12 (EUR 30).
- CAN: one gs_usb CAN-FD adapter (EUR 40) next to the adapter in the OpenArm kit, instead of 2 x PEAK PCAN-USB FD (EUR 520).
- PNOZ status to the Jetson via 2 safe semiconductor outputs + optocouplers to GPIO (already in the BOM) instead of the PNOZ m ES ETH Modbus module (EUR 400).
- Kept because nothing cheaper passes: Siemens 3RT2036 (S2) contactors (45 A worst-case break at 54.75 V; S0 only ~35 A), Mean Well DDR-480C-24 (only DIN unit with 720 W for 5 s at 48 V in), class T main fuse (2.55 kA Isc), 15s 30 Ah pack (C-rate and 6 h barista).

| Lever | EUR saved | Mass | What we lose / risk added | Verdict |
|---|---|---|---|---|
| Safety logic: 2 x Schmersal SRB-E-301ST configurable safety relays (PL e, stop cat. 0/1 delay, EDM) instead of PNOZmulti 2 B0 + EF 4DI4DOR | 460 | -0.1 kg | no programmable logic: fixed SS1-t delay, simpler mode handling; scanner field sets switched by the Jetson (non-safety, as now). Same PL d target; recompute in SISTEMA. Prices estimated | **in LEAN** |
| Shells: dyed/unpainted MJF PA12 instead of painted SLS | 400 | +0.0 kg | appearance only | **in LEAN** |
| EMC input filter (Schaffner FN2200 class) bought only if the EMC pre-scan fails | 60 | -0.2 kg | risk of a re-spin after the pre-scan | **in LEAN** |
| Drop the 2 DRDN40-24 ORing modules (27.5 V clamp alone keeps the arm bus below the DDR OVP) | 110 | -0.6 kg | regen current then reaches the DDR-480C output; needs a bench test that the DDR tolerates it without OVP latch | option (not in lean) |
| Mount the two DDR-480C upright (vertical rating) and drop the 2 fans | 24 | -0.1 kg | needs ~130 mm height in the base layout (CAD change) | option (not in lean) |
| Coffee brewed at the dock (stock 230 V machine) instead of the on-board 24 V module | 763 | -7.3 kg | no brewing on the move; robot must go to the dock per order; machine next to the AgileX dock. Faster to certify | option (not in lean) |
| Jetson Orin Nano Super 8 GB dev kit instead of Orin NX 16 GB | 640 | -0.1 kg | 8 GB RAM / 67 TOPS: cannot run depth + detection + arm policy + ASR concurrently at target rates; policies must be smaller or offloaded | option (not in lean) |
| Pack 15s4p 24 Ah (cells >= 2.5 C pulse) instead of 15s5p 30 Ah | 230 | -2.6 kg | P2 barista autonomy ~5.8 h (< 6 h target); all-peak 2.3 C needs higher-rate cells | option (not in lean) |
| Cheaper PL d safety scanners (e.g. IDEC SE2L / Hokuyo UAM class) instead of 2 x nanoScan3 Pro I/O | 1,000 | +0.0 kg | prices unverified; new integration, fewer field sets, less mature ROS 2 driver; must still be Type 3 / PL d | option (not in lean) |
| ONE nanoScan3 instead of two | 2,300 | -0.7 kg | 275 deg field leaves an ~85 deg blind sector; people approach the coffee backpack from behind and the arms need 360 deg separation monitoring. No safety argument | **NOT acceptable** |
| Remove PNOZ / contactors (rely on the Damiao firmware stop) | 1,300 | -1.2 kg | no PL d stop function: not certifiable | **NOT acceptable** |
| Cheaper arms than OpenArm 2.0 | 0 | +0.0 kg | OpenArm (EUR 5,950 for two arms incl. torso) is already the cheapest validated option; certified arms (UR3e) cost ~4-6x | **NOT acceptable** |

**LEAN configuration (barista kept): EUR 30,949** sum of parts = standard 31,869 - 920 (-0.3 kg); excluding AgileX charging kit / auto-charging pile + NAVIS module (prices not published).
Lean without on-board coffee (brew at the dock): EUR 30,195.

## Subtotals by section

| Section | EUR |
|---|---|
| A. Mobile base | 12,480 |
| B. Arms and end effectors | 5,950 |
| C. Compute, perception, comms | 1,535 |
| D. Face and UI | 72 |
| E. Coffee backpack (barista) | 290 |
| F. Power | 2,602 |
| G. Safety | 5,745 |
| H. Wiring and distribution | 187 |
| I. Shells (SLS/MJF PA12, painted) | 971 |
| J. Docking station | 0 |
| K. Structure (custom parts) | 1,930 |
| L. Fasteners and hardware | 107 |

## Configurations (deltas vs barista default)

| Configuration | Delta EUR | What changes |
|---|---|---|
| Logistics / kitting (no coffee) | -904 | remove all `barista` lines (backpack structure, 24 V machine, shuttle, coffee relay/fuse/supply) |
| Coffee brewed at the dock (option C) | -754 | remove backpack; add a stock 230 V capsule machine next to the charging dock (~150) |
| Archived: RB-THERON instead of Ranger Mini (dock included) | +13,470 | EUR 25,950 - 12,480; plus the unknown AgileX kit price is no longer needed |
| 2x ORCA Hand v2 instead of grippers | +6,500 to +8,300 | FEASIBILITY.md; needs one 12 V 120 W DC-DC per hand (+100) and fits the power budget only at reduced arm caps |
| 2x Pollen AmazingHand | +400 to +500 | FEASIBILITY.md; 5 V 2 A per hand from a 5 V DC-DC (+30) |
| 2x RealSense D405 wrist upgrade | +540 | FEASIBILITY.md (estimate) |

## How double counting was avoided

Every physical item has exactly one priced line. CAD rows that duplicate a priced line are mapped, not summed:

| CAD part | Priced in |
|---|---|
| `B00_ranger_mini3_base` | A. Mobile base |
| `OA_body_link0` | B. OpenArm kit |
| `E01_battery_48V_15s30Ah_LFP` | netlist PACK |
| `E02_dcdc_DDR480C_A` | netlist DCDC_ARM |
| `E03_dcdc_DDR480C_B` | netlist DCDC_ARM |
| `E04_din_rail_pnoz` | F. Power / DIN rail line |
| `E05_pilz_PNOZ_mB0` | netlist PNOZ |
| `E06_contactor_K1` | netlist K_ARM |
| `E07_contactor_K2` | netlist K_ARM |
| `E08_jetson_agx_orin_module` | C. Jetson |
| `E09_orion_tr_48_48_6` | netlist ORION_4848 |
| `S02_nanoScan3_0` | netlist SCANNER |
| `S02_nanoScan3_1` | netlist SCANNER |
| `S05_orbbec_gemini_336L` | C. Gemini 336L |
| `S07_coffee_machine_inissia_EN80` | E. 24 V capsule machine |
| `S08_MGN12_rail_190` | E. MGN12 |
| `S09_MGN12H_carriage` | E. MGN12 |
| `S10_actuonix_P16_150` | E. Actuonix |
| `S10b_actuonix_rod` | E. Actuonix |
| `E11_dcdc_DDR480C_coffee` | netlist DCDC_COF |
| `E12_dcdc_S24_CPU_5V` | netlist DCDC_S24 |
| `E13_ethernet_switch` | C. Ethernet switch line |

Removed (not summed):

| Item | Reason |
|---|---|
| P17_insta360_mast | mast not needed once the Insta360 X4 is removed (fisheyes mount in the head shell) |
| S04_insta360_X4 | replaced by 2 UVC fisheyes (FEASIBILITY.md section 5) |

- Electrical items exist once, in `electrical/netlist_rangermini.yaml`. Its `load` placeholders (OpenArm, Jetson, base) carry price 0 and are skipped.
- The FEASIBILITY.md swaps are applied once:
  - Insta360 X4 -> 2 UVC fisheyes
  - +2 PCAN-USB FD + transceivers
  - +PNOZ m ES ETH
  - +Ethernet switch
  - HUB75 face
  - coffee MCU
  - The FEASIBILITY '+1,500' battery/DC-DC/charger lump is **not** added: all power parts are itemised in the netlist.
- Custom-part prices use a per-process cost model (fixed + EUR/kg; see `make_bom.py` `PROC_MODEL`). These are prototype estimates, not quotes.

## Lines

| Section | Item | MPN | Qty | Unit EUR | Total EUR | Config | Source |
|---|---|---|---|---|---|---|---|
| A | AgileX Ranger Mini 3.0 (LFP 48 V 24 Ah, 120 kg payload, 4WD/4WS, accessory 46-50 V <= 15 A / 720 W) | Ranger Mini 3.0 | 1 | 12,480.00 | 12,480.00 | all | https://www.generationrobots.com/en/404051-ranger-mini-mobile-robot-ugv.html (EUR 12,480 excl. VAT, via cad/BASE_OPTIONS.md) |
| B | Enactic OpenArm 2.0 bimanual (2 arms, torso body_link0, 2 grippers, wrist cameras, 1 USB-CANFD) incl. shipping/duties | OpenArm 2.0 bimanual | 1 | 5,950.00 | 5,950.00 | all | README v7 BOM (USD 6,000 by e-mail order + shipping/duties); https://docs.openarm.dev/purchase |
| C | NVIDIA Jetson Orin NX 16 GB module + compact carrier (replaces AGX Orin 64 GB) | 900-13767-0000-000 + carrier TBD | 1 | 900.00 | 900.00 | all | estimate (Orin NX 16 GB module ~USD 600-700 + carrier ~USD 150-250; not quoted) |
| C | Orbbec Gemini 336L stereo depth camera | Gemini 336L | 1 | 340.00 | 340.00 | all | https://store.orbbec.com/products/gemini-336l (USD 379) |
| C | USB UVC fisheye camera ~180 deg 1080p (front + back), replaces Insta360 X4 | Arducam/e-con class | 2 | 50.00 | 100.00 | all | estimate (FEASIBILITY.md section 3.7 option A) |
| C | USB CAN-FD adapter, SocketCAN gs_usb class (CANable 2.0 / candleLight FD) for the 2nd arm bus (the OpenArm kit ships one) | CANable 2.0 class | 1 | 40.00 | 40.00 | all | estimate; mainline Linux gs_usb driver |
| C | 3.3 V CAN transceiver module for the Orin NX CAN (pack BMS bus) | SN65HVD230 class | 1 | 15.00 | 15.00 | all | estimate |
| C | Industrial Ethernet switch 5-8 port, 24 V DIN (scanners, PNOZ, Jetson) |  | 1 | 80.00 | 80.00 | all | estimate (FEASIBILITY.md section 5) |
| C | Powered USB 3 hub, 7 port, 12 V input |  | 1 | 60.00 | 60.00 | all | estimate (FEASIBILITY.md section 6: 9-11 USB devices) |
| D | HUB75 32x16 P4 RGB LED panel |  | 1 | 20.00 | 20.00 | all | estimate |
| D | ESP32-S3 HUB75 driver board (Matrix Portal S3 class) |  | 1 | 25.00 | 25.00 | all | estimate (FEASIBILITY.md section 3.10) |
| D | GC9A01 1.28 in round displays (eyes) |  | 2 | 6.00 | 12.00 | all | README v3/v7 (5-10 EUR each) |
| D | LED strips / mustache diffuser LEDs |  | 1 | 15.00 | 15.00 | all | estimate (README v7 line 40 EUR incl. eyes) |
| E | 24 V DC capsule machine, Nespresso-compatible, 300 W (truck type) |  | 1 | 120.00 | 120.00 | barista | https://www.truckstyler-shop.de/Suitable-for-Nespresso-Truck-24V-coffee-capsule-machine?slotID=2 (EUR 119.99) - CAD envelope is a De'Longhi Inissia EN80 (230 V); the electrical design requires the 24 V DC machine. CE / EN 60335-2-15 not stated by seller |
| E | Actuonix P16-150-64-12-P linear actuator (cup shuttle) | P16-150-64-12-P | 1 | 95.00 | 95.00 | barista | estimate (Actuonix list ~USD 100) |
| E | HIWIN MGN12 rail L=190 + MGN12H carriage | MGN12-190 + MGN12H | 1 | 45.00 | 45.00 | barista | estimate |
| E | Coffee MCU: RP2040 + DRV8871 H-bridge + relay + cup-present sensor + 12 V buck |  | 1 | 30.00 | 30.00 | barista | FEASIBILITY.md section 5 (+30) |
| E | Paper cups + capsules starter stock |  | 1 | 0.00 | 0.00 | barista | consumable, not counted |
| F | 15s5p LiFePO4 48 V 30 Ah 1.44 kWh, flat 270x400x75 mm, <= 13 kg, IP54 case, CAN BMS, cells >= 1.2 C cont / 2 C 10 s, IEC 62619 + UN 38.3 + CE/EMC test reports required | GIO-BAT-15S30 (spec), 15s5p LFP 32700 6 Ah power cells | 1 | 1,150.00 | 1,150.00 | all | estimate - price estimate |
| F | cell V/T monitoring, SoC/SoH, charge/discharge FETs, bus precharge on wake, CAN to Jetson and dock charger, key/enable input | pack BMS, MOSFET, CAN 2.0B, with precharge | 1 | 0.00 | 0.00 | all | estimate - price estimate |
| F | JLLN060.T | JLLN060.T | 1 | 30.00 | 30.00 | all | https://littelfusesales.com/assets/content/vendorAssets/pdf/littelfuse_fuse_jlln_jlls_datasheet.pdf |
| F | JLLN035.T | JLLN035.T | 1 | 25.00 | 25.00 | all | https://littelfusesales.com/assets/content/vendorAssets/pdf/littelfuse_fuse_jlln_jlls_datasheet.pdf |
| F | SPF020 (10x38 gPV) | SPF020 (10x38 gPV) | 2 | 6.00 | 12.00 | all | estimate - price estimate |
| F | SPF015 | SPF015 | 1 | 6.00 | 6.00 | all | estimate - price estimate |
| F | SPF012 | SPF012 | 3 | 6.00 | 18.00 | all | estimate - price estimate |
| F | SPF006 | SPF006 | 2 | 6.00 | 12.00 | all | estimate - price estimate |
| F | SPF003 | SPF003 | 1 | 6.00 | 6.00 | all | estimate - price estimate |
| F | LPXV series 10x38 DIN holder (1-pole) | LPXV series 10x38 DIN holder (1-pole) | 8 | 9.00 | 72.00 | all | estimate - price estimate |
| F | LFT60 class T holder (35-60 A) | LFT60 class T holder (35-60 A) | 2 | 35.00 | 70.00 | all | https://littelfusesales.com/assets/content/vendorAssets/pdf/littelfuse_fuse_jlln_jlls_datasheet.pdf |
| F | 0257025 (ATO 32 V) | 0257025 (ATO 32 V) | 2 | 1.00 | 2.00 | all | estimate - price estimate |
| F | 0257020 | 0257020 | 1 | 1.00 | 1.00 | barista | estimate - price estimate |
| F | 0257010 | 0257010 | 1 | 1.00 | 1.00 | all | estimate - price estimate |
| F | 0257005 | 0257005 | 2 | 1.00 | 2.00 | all | estimate - price estimate |
| F | SB120 grey + lockout cover (service disconnect, open only after key-off) | SB120 grey + lockout cover (service disconnect, open only after key-off) | 1 | 25.00 | 25.00 | all | estimate - price estimate |
| F | key selector 2-pos (BMS enable) | key selector 2-pos (BMS enable) | 1 | 30.00 | 30.00 | all | estimate - price estimate |
| F | DRDN40-24 (ORing module per arm bus) | DRDN40-24 (ORing module per arm bus) | 2 | 55.00 | 110.00 | all | estimate - price estimate |
| F | 33.6-67.2 V in, 24 V 20 A, 30 A 5 s, 92 %, remote ON/OFF, DIN rail | DDR-480C-24 | 2 | 140.00 | 280.00 | all | https://www.meanwell.com/Upload/PDF/DDR-480/DDR-480-SPEC.PDF |
| F | DDR-120C-24 | DDR-120C-24 | 1 | 50.00 | 50.00 | all | https://www.meanwell.com/Upload/PDF/DDR-120/DDR-120-SPEC.PDF |
| F | DDR-60L-12 | DDR-60L-12 | 1 | 30.00 | 30.00 | all | https://www.meanwell.com/Upload/PDF/DDR-60/DDR-60-SPEC.PDF |
| F | DDR-60L-5 | DDR-60L-5 | 1 | 30.00 | 30.00 | all | https://www.meanwell.com/Upload/PDF/DDR-60/DDR-60-SPEC.PDF |
| F | DDR-480C-24 | DDR-480C-24 | 1 | 140.00 | 140.00 | barista | https://www.meanwell.com/Upload/PDF/DDR-480/DDR-480-SPEC.PDF |
| F | 62.32.9.024.0040 (16 A, coffee 24 V cut, PNOZ safe output) | 62.32.9.024.0040 (16 A, coffee 24 V cut, PNOZ safe output) | 1 | 25.00 | 25.00 | barista | estimate - price estimate |
| F | 62.32.9.024.0040 (16 A power relay) precharge bypass | 62.32.9.024.0040 (16 A power relay) precharge bypass | 1 | 25.00 | 25.00 | all | estimate - price estimate |
| F | HS50 47R J | HS50 47R J | 1 | 8.00 | 8.00 | all | estimate - price estimate |
| F | shunt regulator 27.5 V + Arcol HS100 1R8 | shunt regulator 27.5 V + Arcol HS100 1R8 | 2 | 60.00 | 120.00 | all | estimate - price estimate |
| F | XT60PW-M/F (arm 24 V at column base) | XT60PW-M/F (arm 24 V at column base) | 2 | 3.00 | 6.00 | all | estimate - price estimate |
| F | SB120 (pack <-> distribution, doubles as MSD) | SB120 (pack <-> distribution, doubles as MSD) | 1 | 0.00 | 0.00 | all | estimate - price estimate |
| F | Powerpole PP45 / PP15 (24 V, 12 V branches) | Powerpole PP45 / PP15 (24 V, 12 V branches) | 10 | 2.00 | 20.00 | all | estimate - price estimate |
| F | 60x60x15 mm 24 V DC fan (e.g. Sunon MF60152V1 class) + guard | 60x60x15 mm 24 V DC fan (e.g. Sunon MF60152V1 class) + guard | 2 | 12.00 | 24.00 | all | estimate - price estimate |
| F | Orion-Tr Smart 48/48-6 (isolated DC-DC charger, LFP profile 54.0 V, ~290 W) | Orion-Tr Smart 48/48-6 (isolated DC-DC charger, LFP profile 54.0 V, ~290 W) | 1 | 260.00 | 260.00 | all | estimate - price estimate |
| F | DIN rail 35x7.5 + end stops (E04 in CAD) | EN 60715 | 2 | 6.00 | 12.00 | all | estimate |
| G | 3RT2036-1BB40 (S2, 24 V DC coil, 1NO+1NC mirror) | 3RT2036-1BB40 (S2, 24 V DC coil, 1NO+1NC mirror) | 2 | 120.00 | 240.00 | all | estimate - price estimate |
| G | 772100 PNOZ m B0 | 772100 PNOZ m B0 | 1 | 500.00 | 500.00 | all | netlist.yaml |
| G | 772143 PNOZ m EF 4DI4DOR (relay outputs) | 772143 PNOZ m EF 4DI4DOR (relay outputs) | 1 | 300.00 | 300.00 | all | estimate - price estimate |
| G | NANS3-CAAZ30AN1 (1100334) Pro I/O, 128 field sets | NANS3-CAAZ30AN1 (1100334) Pro I/O, 128 field sets | 2 | 2,300.00 | 4,600.00 | all | https://www.sick.com/media/pdf/0/80/980/dataSheet_NANS3-CAAZ30AN1_1100334_en.pdf |
| G | M22-PV/K02 + M22-XGPV yellow guard (2 NC) | M22-PV/K02 + M22-XGPV yellow guard (2 NC) | 2 | 35.00 | 70.00 | all | estimate - price estimate |
| G | M22-DL-B + M22-K10 (blue illuminated reset) | M22-DL-B + M22-K10 (blue illuminated reset) | 1 | 20.00 | 20.00 | all | estimate - price estimate |
| G | Optocouplers 24 V -> 3.3 V for PNOZ status into Jetson GPIO |  | 1 | 15.00 | 15.00 | all | estimate (FEASIBILITY.md section 6) |
| H | H07V-K 16 mm2 (or OLFLEX HEAT 125 SC) [m] | H07V-K 16 mm2 (or OLFLEX HEAT 125 SC) [m] | 2 | 5.00 | 10.00 | all | estimate - price estimate |
| H | H07V-K 10 mm2 [m] | H07V-K 10 mm2 [m] | 3 | 3.50 | 10.50 | all | estimate - price estimate |
| H | H07V-K 6 mm2 [m] (arm feeds through column) | H07V-K 6 mm2 [m] (arm feeds through column) | 8 | 2.20 | 17.60 | all | estimate - price estimate |
| H | H05V-K 0.75-2.5 mm2 assorted [m] | H05V-K 0.75-2.5 mm2 assorted [m] | 30 | 0.80 | 24.00 | all | estimate - price estimate |
| H | PTFIX / UT DIN distribution block + 2x Cu busbar (B48 +/-) | PTFIX / UT DIN distribution block + 2x Cu busbar (B48 +/-) | 1 | 60.00 | 60.00 | all | estimate - price estimate |
| H | 0 V to chassis single-point bond strap 6 mm2 | 0 V to chassis single-point bond strap 6 mm2 | 1 | 5.00 | 5.00 | all | estimate - price estimate |
| H | FN2200-50 DC/AC filter on arm DC-DC inputs (if class B conducted needed) | FN2200-50 DC/AC filter on arm DC-DC inputs (if class B conducted needed) | 1 | 60.00 | 60.00 | all | estimate - price estimate |
| I | SH01_deck_cover (PA12 (SLS/MJF), 1.244 kg) |  | 1 | 314.00 | 314.00 | all | estimate: process cost model - SLS PA12 2 mm in 2 halves (front/rear), 4 M5 into standoffs; stands on the RB-THERON top inside its outline |
| I | SH02_column_cover_fixed (PA12 (SLS/MJF), 0.061 kg) |  | 1 | 53.00 | 53.00 | all | estimate: process cost model - SLS PA12 2 mm, 2 halves clipped around the profile (T-slot clips) |
| I | SH03_waist_cover (PA12 (SLS/MJF), 0.522 kg) |  | 1 | 155.00 | 155.00 | all | estimate: process cost model - SLS PA12 3 mm, 2 halves, hangs from P02 on 4 lugs with M4 |
| I | SH04a_torso_shell_front (PA12 (SLS/MJF), 0.251 kg) |  | 1 | 95.00 | 95.00 | all | estimate: process cost model - SLS/MJF PA12 3 mm half shell (split x=0, tongue-and-groove seam not modelled), 2 M4 inserts |
| I | SH04b_torso_shell_rear (PA12 (SLS/MJF), 0.274 kg) |  | 1 | 100.00 | 100.00 | all | estimate: process cost model - SLS/MJF PA12 3 mm half shell (split x=0, tongue-and-groove seam not modelled), 2 M4 inserts |
| I | SH05_head_shell (PA12 (SLS/MJF), 0.149 kg) |  | 1 | 73.00 | 73.00 | all | estimate: process cost model - SLS PA12 2.5 mm, painted; smoked PETG visor bonded |
| I | SH06_coffee_housing (PA12 (SLS/MJF), 0.641 kg) |  | 1 | 181.00 | 181.00 | barista | estimate: process cost model - SLS PA12 3 mm (2 pieces), hangs on the shelf edge with 4 M4 inserts |
| J | AgileX charging kit / auto-charging pile + NAVIS module (robot-side kit included) |  | 1 | 0.00 | 0.00 | all | price and datasheet NOT published - quote requested (AGILEX_REQUEST.md) - NOT included in the sum |
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

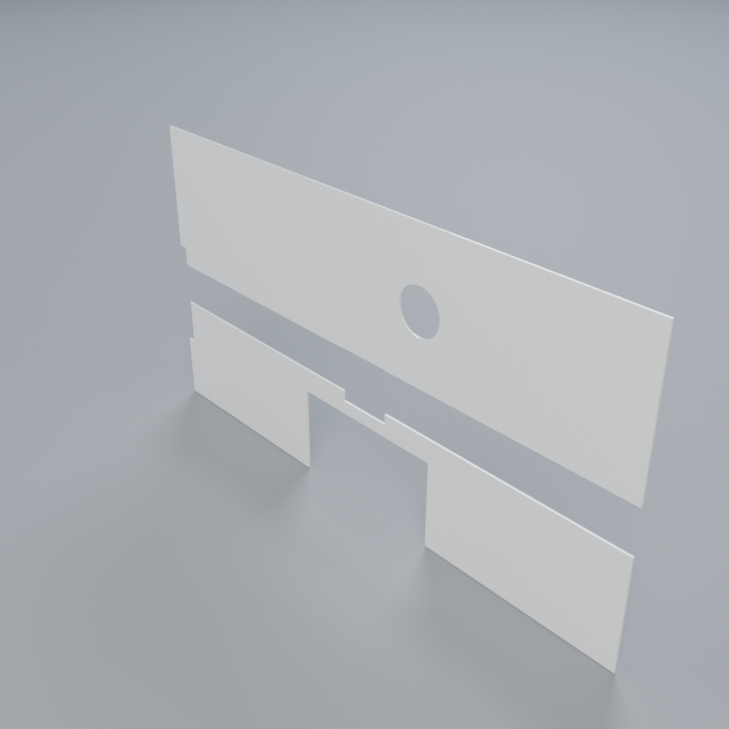
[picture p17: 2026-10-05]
amr/renders/parts/K03_cover_L.png

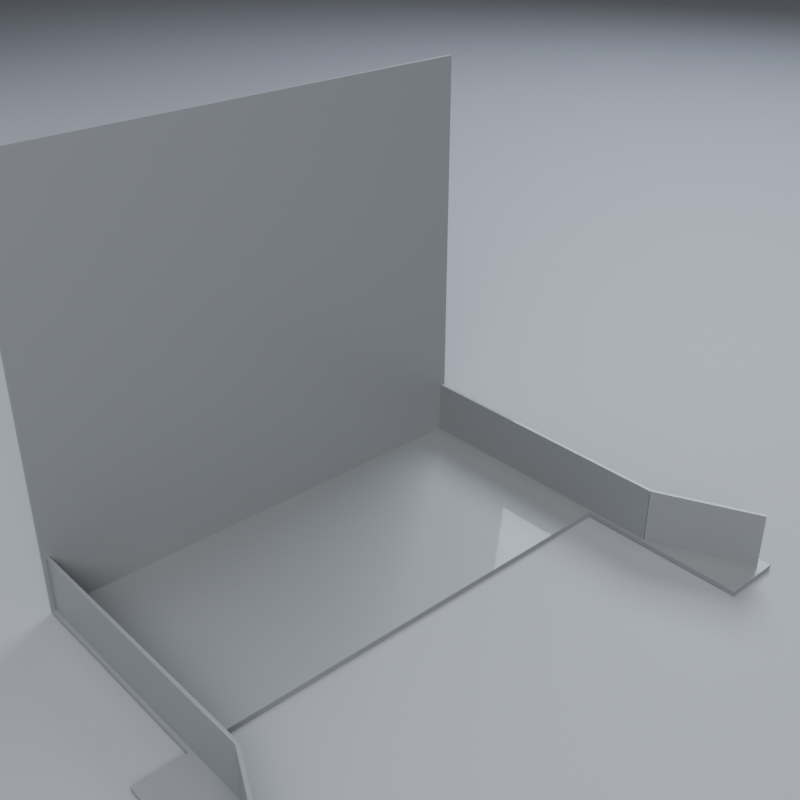
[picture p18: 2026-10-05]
amr/renders/parts/X01_dock_frame.png

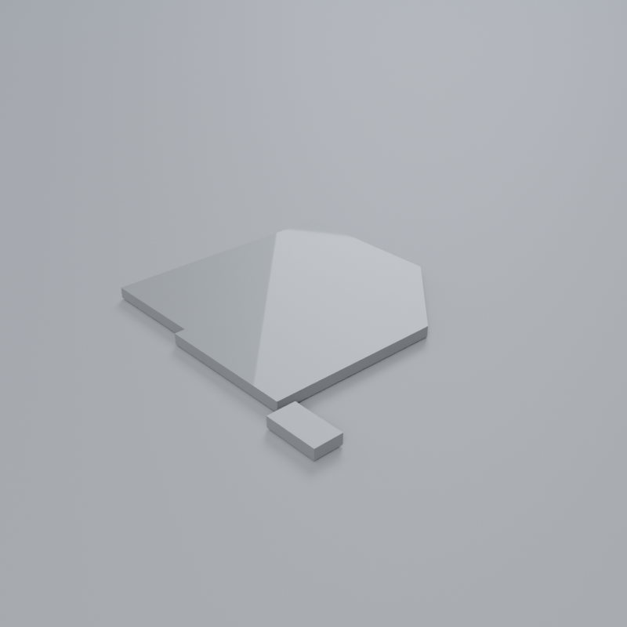
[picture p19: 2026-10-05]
amr/renders/parts/A05_tower_roof_FL.png

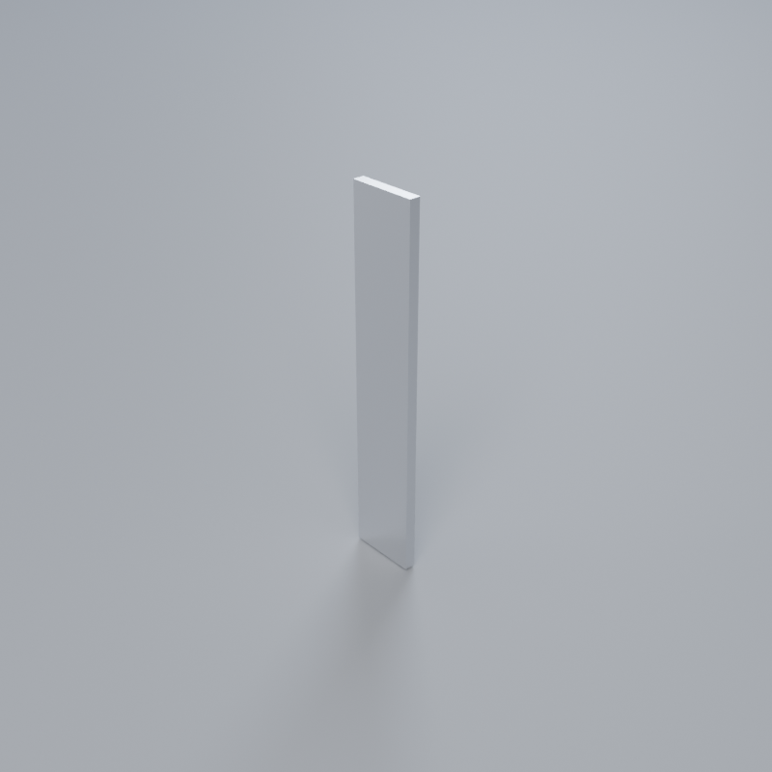
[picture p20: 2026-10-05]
amr/renders/parts/A06_corner_bracket_FL.png

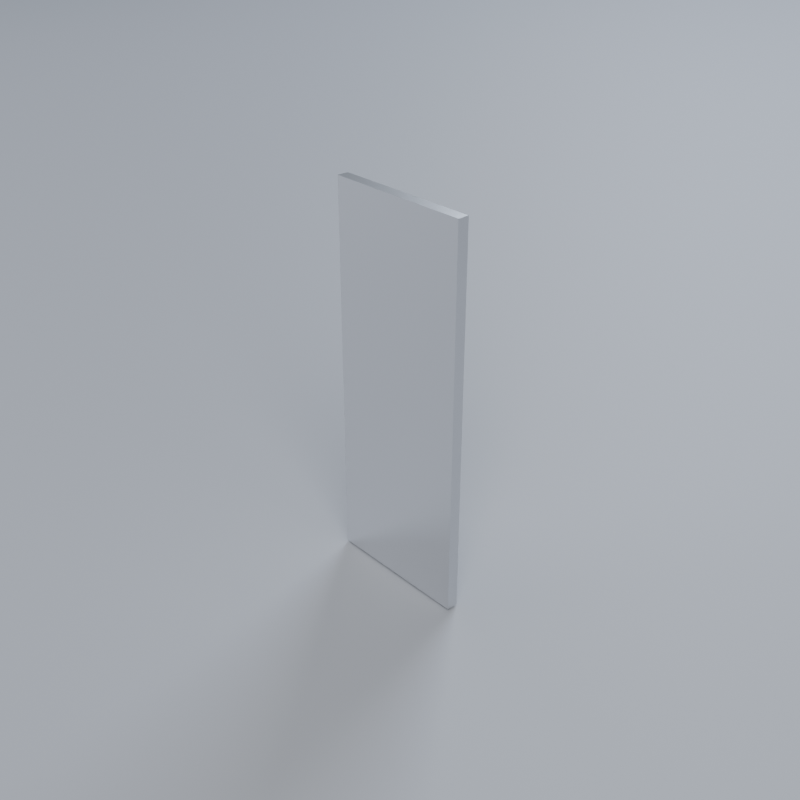
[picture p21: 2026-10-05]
amr/renders/parts/A07_corner_bracket_RR.png

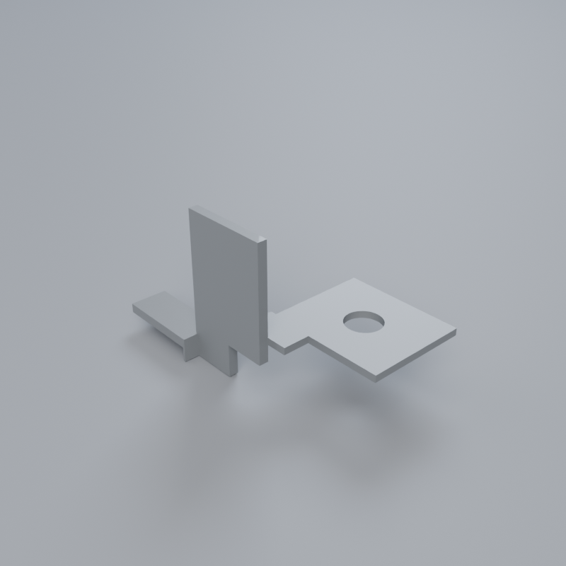
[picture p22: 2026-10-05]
amr/renders/parts/C02_castor_carriage_FL.png

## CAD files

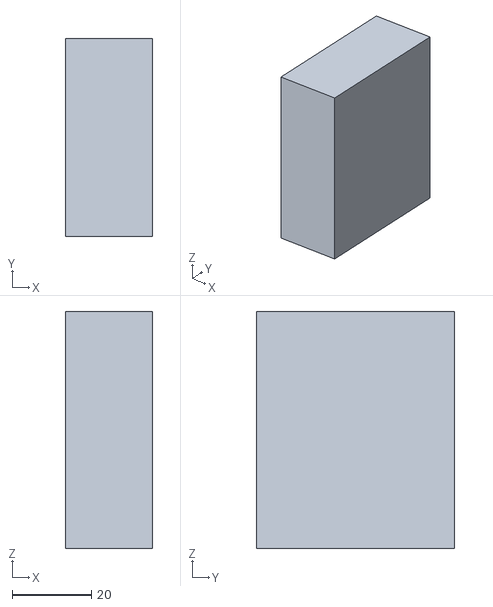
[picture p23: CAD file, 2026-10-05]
amr/out/exploded/E35_RSIG_X0R.stl
22.0 x 50.0 x 60.0

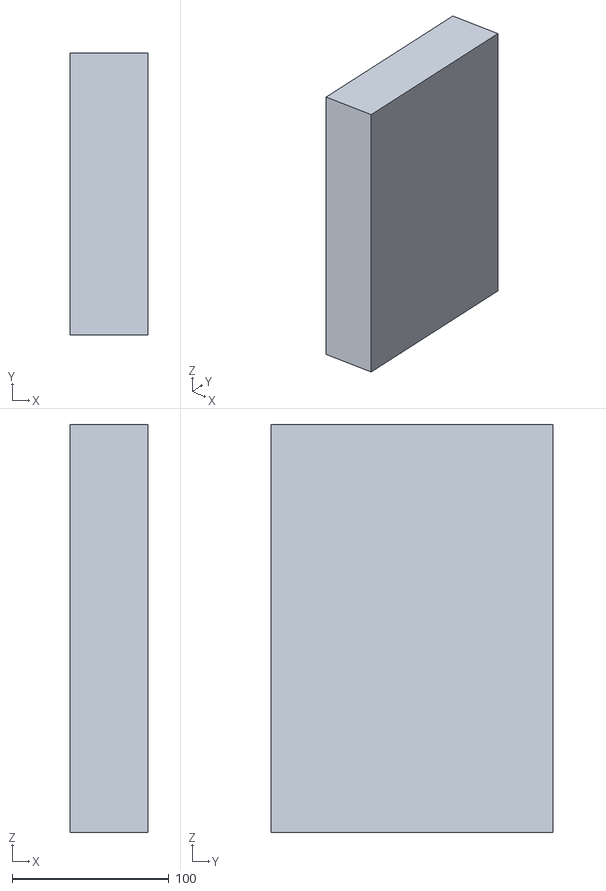
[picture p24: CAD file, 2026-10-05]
amr/out/keepout/KO_B01_F_top_cover_50mm.stl
50.0 x 180.0 x 260.0

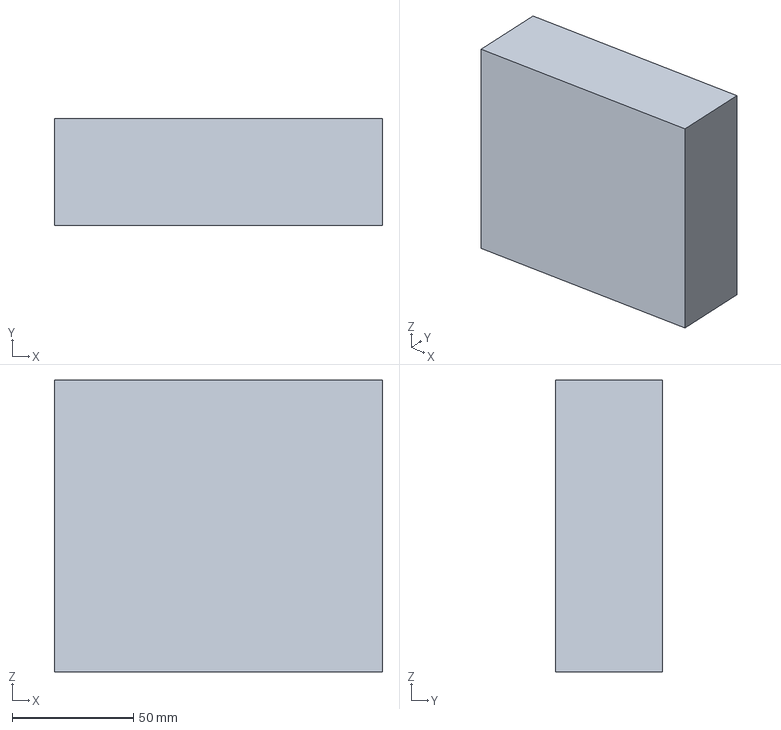
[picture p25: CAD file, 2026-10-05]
amr/out/step/E38_G01_LYNK_II_gateway.step
135.0 x 44.0 x 120.0 mm

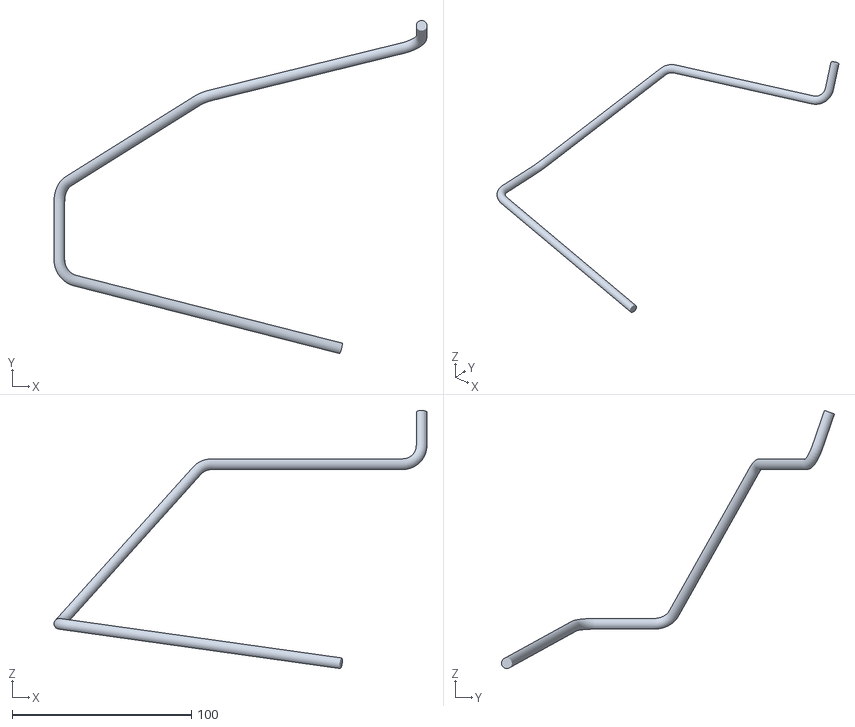
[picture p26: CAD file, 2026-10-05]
amr/out/stl/H10_ethernet_safety_to_deck.stl
208.0 x 185.7 x 143.9

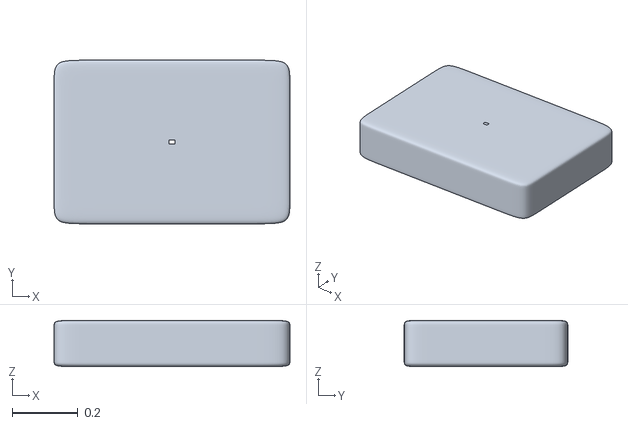
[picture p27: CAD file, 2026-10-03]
assets/shells/deck_cover.obj
0.718 x 0.498 x 0.141

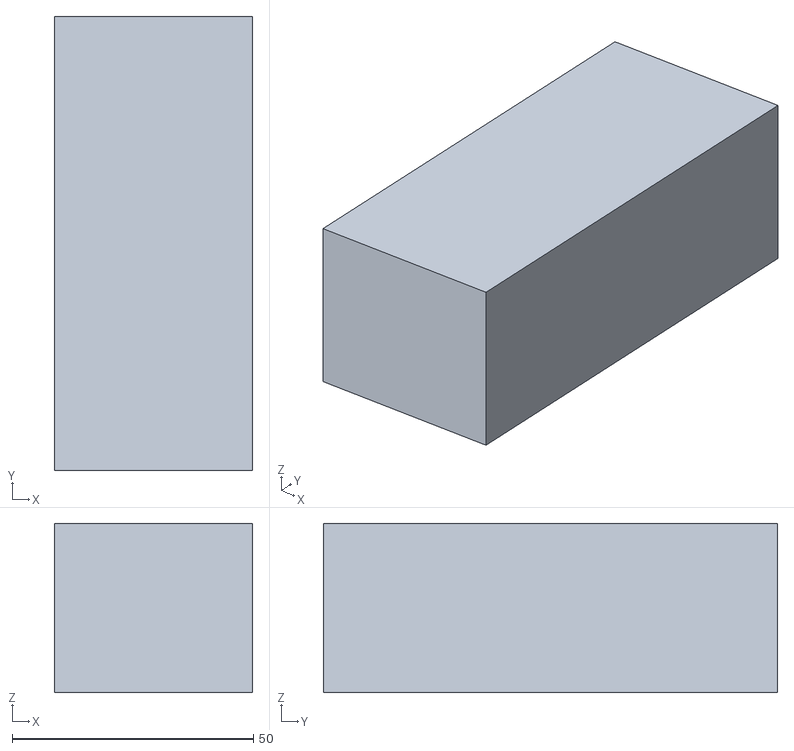
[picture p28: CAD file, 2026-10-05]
amr/out/exploded/E5B_arm_clamp_R_DSR50-5.stl
41.0 x 94.0 x 35.0

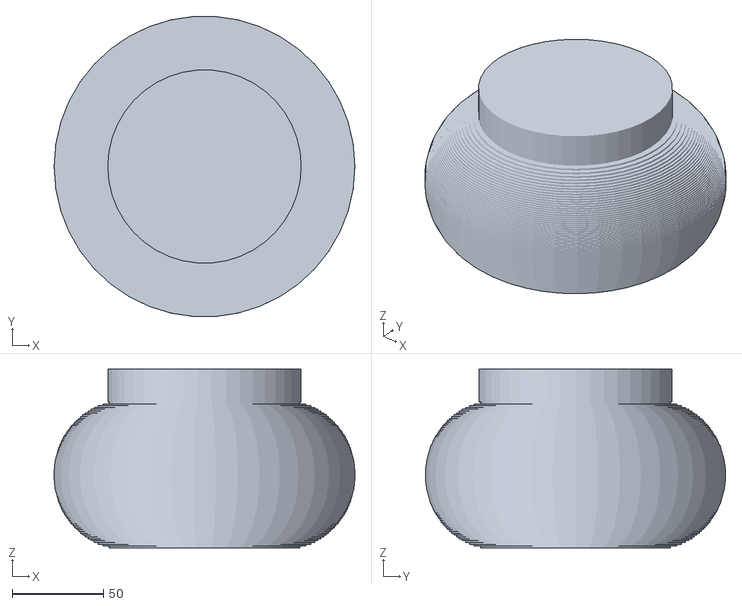
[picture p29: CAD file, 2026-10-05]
amr/out/keepout/KO_C01_swivel_vs_carriage_RR.stl
164.9 x 164.4 x 98.0

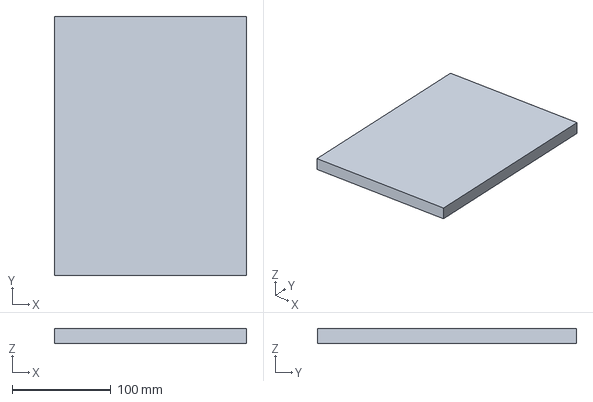
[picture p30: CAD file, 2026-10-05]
amr/out/step/A09_deck_doubler.step
194.0 x 262.0 x 15.0 mm

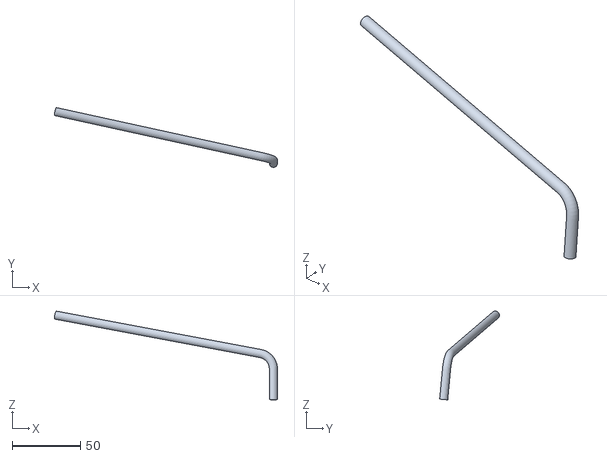
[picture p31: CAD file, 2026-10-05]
amr/out/stl/H09_safety_estops.stl
163.8 x 43.9 x 65.2

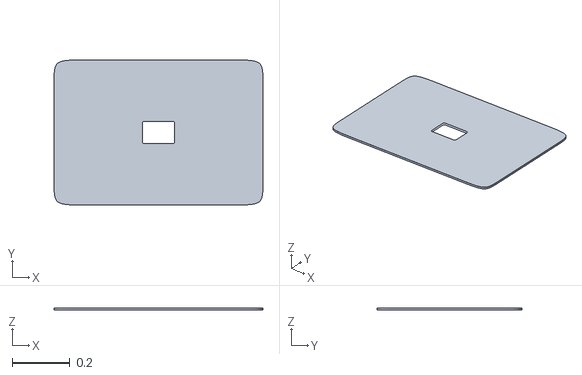
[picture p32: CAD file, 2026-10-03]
assets/shells/led_deck.obj
0.721 x 0.501 x 0.008

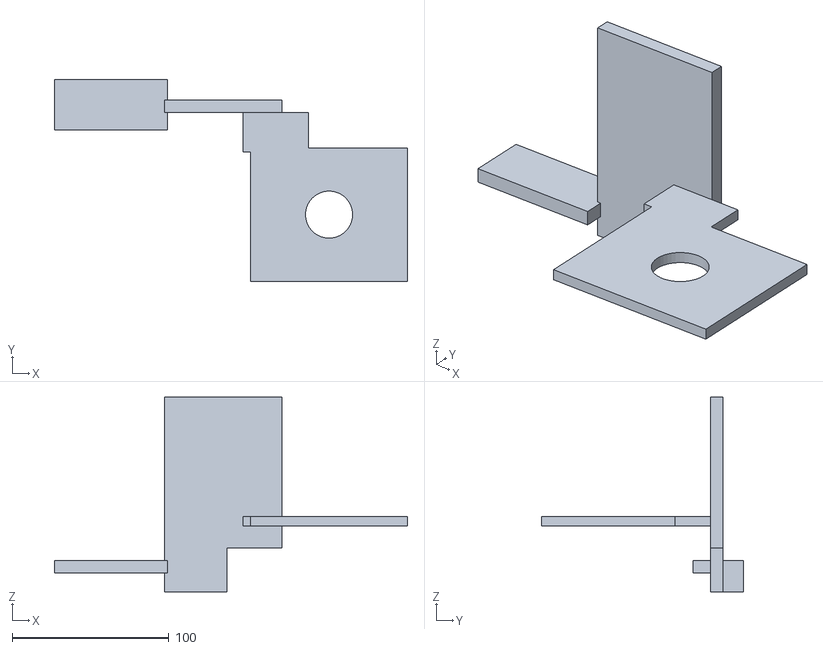
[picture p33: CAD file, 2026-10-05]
amr/out/exploded/C02_castor_carriage_FR.stl
225.0 x 128.5 x 124.0

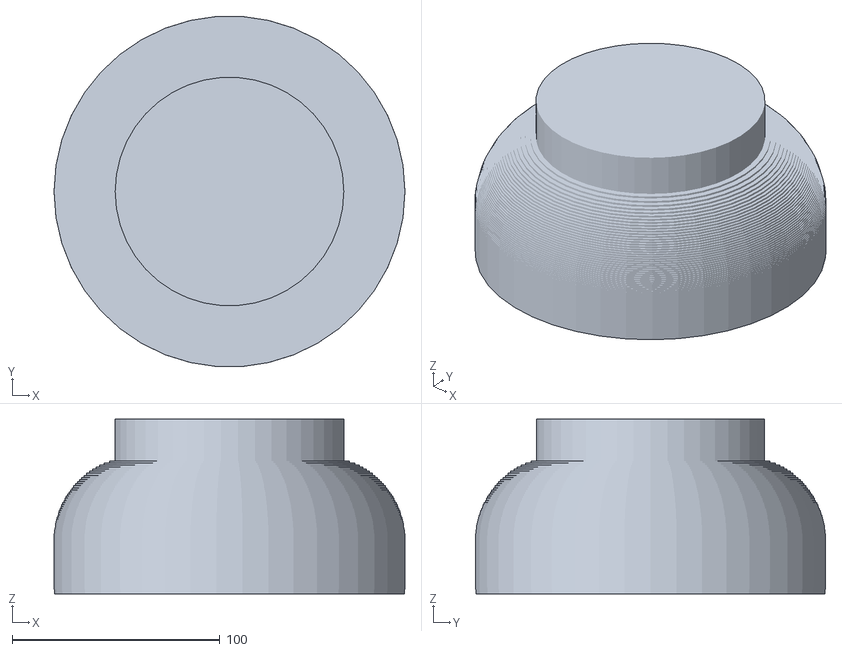
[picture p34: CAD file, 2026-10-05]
amr/out/keepout/KO_C01_swivel_RR.stl
168.9 x 168.4 x 84.0

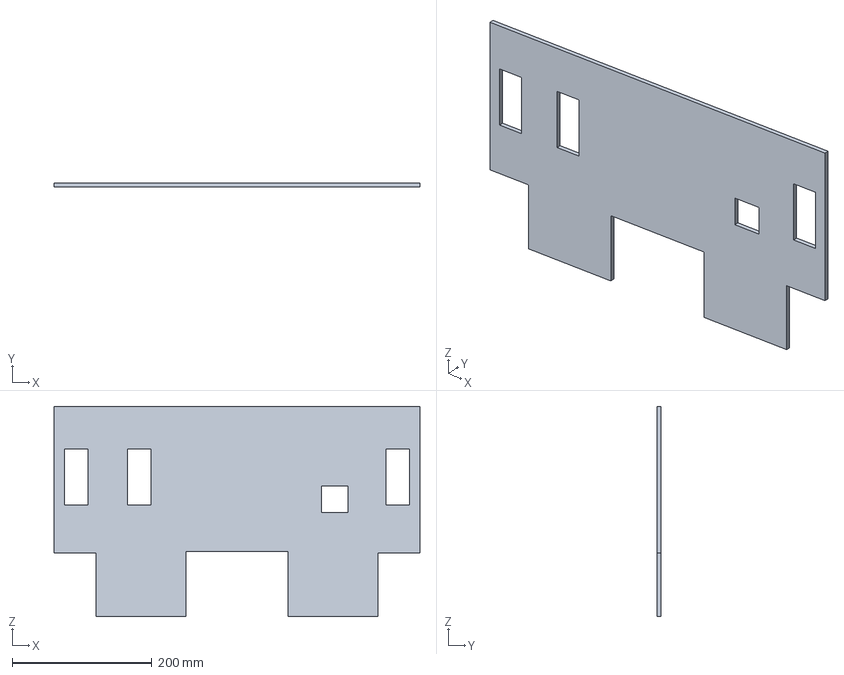
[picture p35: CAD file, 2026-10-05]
amr/out/step/A03_spine_R.step
524.0 x 6.00 x 301.0 mm

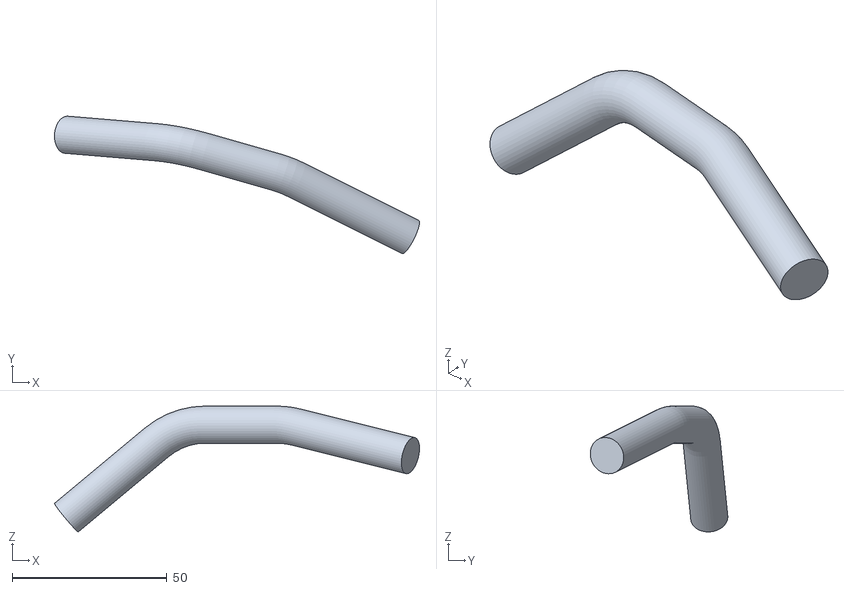
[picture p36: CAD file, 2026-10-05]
amr/out/stl/H06_dock_to_charge_path.stl
117.8 x 44.4 x 40.6

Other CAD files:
assets/shells/tricolor_deck.obj
amr/out/exploded/A05_tower_roof_FL.stl
amr/out/keepout/KO_E58_U6_DDR60L5.stl
amr/out/step/E50_dcdc_arm_R_DDR480C24.step
amr/out/dxf/A01_floor_pan.dxf
amr/out/dxf/A02_top_deck.dxf
amr/out/dxf/A09_deck_doubler.dxf
amr/out/exploded/A01_floor_pan.stl
amr/out/exploded/A02_top_deck.stl
amr/out/exploded/A03_spine_L.stl
amr/out/exploded/A03_spine_R.stl
amr/out/exploded/A04_post_FL.stl
amr/out/exploded/A04_post_FR.stl
amr/out/exploded/A04_post_RL.stl
amr/out/exploded/A05_tower_roof_FR.stl
amr/out/exploded/A05_tower_roof_RL.stl
amr/out/exploded/A05_tower_roof_RR.stl
amr/out/exploded/A06_corner_bracket_FL.stl
amr/out/exploded/A07_corner_bracket_RR.stl
amr/out/exploded/A08_rail_bracket_RL.stl
amr/out/exploded/A09_deck_doubler.stl
amr/out/exploded/A10_rail_bracket_FR.stl
amr/out/exploded/B01_battery_F_DLP-GC2-48V.stl
amr/out/exploded/B01_battery_R_DLP-GC2-48V.stl
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

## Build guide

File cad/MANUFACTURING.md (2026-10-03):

# Giorgio — manufacturing notes and assembly sequence

> **Ranger Mini 3.0 design (current, 2026-10-03):**
> - P01 is 8 mm 6082 on the 2 top rails (16 × M5 countersunk + T-nuts).
> - Fixed column: P29 foot + profile 197 mm + P02 (waterjet + one CNC set-up, no pockets).
> - **SH01 deck cover in laser-cut, bent and powder-coated 1.5 mm aluminium** (cheaper than SLS).
> - Our 15s 30 Ah pack in tray P03; side and rear e-plates P06/P07/P08.
> - Backpack e-plate P30 on 3 catalogue standoffs under the coffee shelf; scanner pods P09 at the front-right and rear-left corners.
> - No sleeve/liners, skirt, bumper or RoboPad.
>
> Cost table and cost-down options: README "Cost drivers".
>
> *Superseded* Ranger Air design changes:
> - P01 is now an 8 mm 6082 "butterfly" plate (waterjet + grid lightening, 8 × M6 countersunk into the base deck).
> - The column is fixed: **P29 foot** (CNC 20 mm, M12 from below, 8 × M6 from the top in counterbores) + profile 292 mm + P02.
> - **SH01 is a 2 mm deck cover** (not a skirt).
> - **No** sleeve weldment W01, liners, battery tray/pack, hold-downs, Tracer charger, RoboPad bracket or bumper.
> - Two 2 mm e-plates: P06 front, P07 rear.
> - Coffee uprights move to x −266…−190.
>
> Rows below for removed parts refer to the archived Tracer design (git 2660c92).
> **Assembly:** P29 + profile + P02 are bolted to P01 on the bench, because the M12 sits under the foot. Then P01 goes onto the Ranger Air (8 × M6 csk).

All part numbers refer to `model.py` (names in `out/bom_parts.csv`). Prototype quantity 1–5 sets; the "series" column
says what changes at 50+ units. Fastener list: `out/bom_fasteners.csv` (generated, with torque/preload in VALIDATION.md).

## Process per part

| Part | Material | Prototype process | Series | Notes |
|---|---|---|---|---|
| P01 base adapter plate | EN AW-6082-T6, 8 mm | waterjet / fibre-laser cut with 11 lightening windows, CNC drill + tap (M5/M6), Ø9 clearance for the 8 column-foot screws, 90° countersinks for the 16 rail screws | same, laser | deburr, black anodise. Flatness 0.3 mm over the column footprint. Lightening windows only where nothing is fixed. |
| W01 column sleeve weldment | 6082-T6 flange 12 mm + EN AW-6060-T66 tube 100×100×3 (EN 755-2) + 2 boss blocks | TIG weld (4043/5356 filler), **then** machine: flange face, 8 × M8 through-taps in the flange, 4 inner liner seats, M10 clamp threads, M16×1.5 plunger thread | same, or a cast/extruded sleeve | HAZ reduces 6082 to ~50% Rp0.2: stresses in the weld are < 5 MPa (see README), fine. Clear anodise after machining, mask threads. |
| S01 column profile | item Profil 8 80×80 leicht 0.0.265.80 | buy cut to 370 mm; drill 7× Ø8.5 index holes at 25 mm pitch; tap core M12 × 30 | same | core bore Ø ESTIMATE 10.2 — check on delivery. |
| P13/P14/P15 liners, gib, guide pads | POM-C 6.8 mm | CNC from sheet | same | bonded (3M DP490) — trapped between tube and profile; gib strip floats under the M10 clamp screws. |
| P02 column-to-torso bracket | 6082-T6, 20 mm | 3-axis CNC: 80×80 spigot pocket (H8 fit on the profile), underside lightening pockets (6 mm web), M12 counterbore, 8× Ø6.6, 4× M4 | same | the spigot gives location + shear; the M12 gives clamp. |
| P03 battery tray | EN AW-5754-H22, 2 mm | laser + press brake (8 bends, flanges outward) | same | EPDM pads (P04) on the floor and on the side walls (10 mm gap). |
| P05 battery hold-down bars (2) | 5754-H22, 3 mm | laser + 2 bends | same | M5 + ISO 4032 nut through the tray wall. |
| P06/P07/P08 electronics plates | 5754-H22, 2 mm | laser, PEM nuts M4 (components) | same | pre-wired on the bench, dropped in as modules (4× M5 each). |
| P09 scanner pod brackets (2) | 5754-H22, 3 mm | laser + bends (U-cradle, back plate, top flange) | same | 4× M5 into the nanoScan3 side threads (max 7.5 mm insertion, SICK). Alignment: slotted top flange recommended after first fit (SICK alignment kit 2a 2111769 as alternative). |
| P10 charging-collector bracket | 5754-H22, 4 mm | laser + 1 bend | same | Roboteq RPCOL90-100 on 4× M4 (74×56 pattern; vertical pitch to be confirmed on the real part). |
| P11 skirt standoffs (6) | 6082-T6 Ø14 | lathe, M5 male stud bottom / M5 tapped top | same | lengths differ per position (see BOM). |
| SH01 base skirt | prototype: SLS PA12 3 mm in 4 segments bonded with internal splice strips; series: vacuum-formed ABS/PC 4 mm on a CNC mould | — | thermoform | 750×660×250 mm does not fit any SLS/MJF bed (EOS P396: 340×340×600, HP 5200: 380×284×380). Open bottom, scanner-pod cut-outs, open scan slots (no window in front of a safety scanner). |
| P12 bumper | EPDM D-profile | buy by the metre, bond | same | |
| SH02 fixed column cover, SH03 waist cover, SH04 torso shell, SH05 head shell, SH06 coffee housing | PA12 | SLS/MJF 2.0 mm (skirt 2.5 mm), each split in 2 halves (front/rear or left/right) to fit 380×284×380 bed and to assemble around the arms/column; Kerb Konus 860 M4 heat-set inserts in bosses | RIM PU or injection-moulded ABS for >200 units | vapour smoothing + primer + paint (warm white soft-touch, accent bands). Min wall around inserts 2.5 mm (Kerb Konus). |
| P16 head neck plate | 5754-H22, 3 mm | laser | same | |
| P17 Insta360 mast | 6082-T6 | CNC: Ø14 rod + 56×66×8 foot in one piece, 1/4"-20 stud at top | same | |
| P18 Gemini bracket | 5754-H22, 2.5 mm | laser + 3 bends | same | M4 into the camera back: **max 4 mm insertion, 0.4 N·m** (Orbbec). |
| P19 tray carrier | 5754-H22, 3 mm | laser + bends | same | 4× M6 into T-nuts in the OpenArm post front slot (slot type ASSUMED). |
| P20 tray halves L/R | PA12 MJF | MJF (309×98×72 fits the bed) | injection-moulded POM for series | 3 pockets 60×60, 16 mm 45° lead-in. Located by 2 ISO 7379 Ø8 shoulder screws (S06) each + 1 GN 617 spring plunger: lift-off quick release. |
| P21 coffee shelf | 6082-T6, 6 mm | waterjet + drill/tap M3/M4 | laser | |
| P22 coffee uprights (2) | 5754-H22, 2 mm | laser + 4 bends (C-channel with feet) | same | pass through slots in the skirt top. |
| P23 rail riser | 6082 flat 20×4 | saw + drill | same | MGN12 rail (S08) on top. |
| P24 shuttle cup carrier | PA12 MJF | MJF | same | cup cradle ring Ø72, arm to the MGN12H carriage, lug for the actuator rod end. |
| P25 actuator rear bracket | 5754-H22, 3 mm | laser + 1 bend | same | |
| P26 cup-stack holder | PA12 MJF | MJF, 3 inserts M4 in a 14 mm foot | same | |

Tolerances (general): ISO 2768-mK for machined parts, ISO 2768-m + DIN 6935 bend radii for sheet; spigot pocket P02 80 H8;
liner bore after welding 90.0 +0.2/0; clearance holes ISO 273 medium; tapped holes 6H.

## Assembly sequence (one robot)

1. **Bench sub-assemblies**: electronics plates P06/P07/P08 with DC-DCs, PNOZ (DIN rail), contactors, Jetson, charger, pre-wired and tested; battery in tray P03 with EPDM pads and hold-down bars P05; scanner pods (nanoScan3 + P09); collector + P10; coffee module (shelf P21 + uprights P22 + rail/riser + carriage + cup carrier + actuator + bracket + cup holder; machine last).
2. **Column**: bond POM liners in the sleeve top (W01) and guide pads on the profile bottom (S01); insert the profile from the top; fit gib strip, M10 clamp levers and the GN 617 index plunger (lock at lift 0).
3. **Adapter plate**: bolt W01 foot flange to P01 from below (8× DIN 7984 M8×20 into the flange threads, 20 N·m) on the bench, before P01 goes on the Tracer. Slide 16 M5 T-nuts into the Tracer rails, lay P01 on the rails, 16× M5×16 countersunk, **0.6 N·m** (T-nut allowable is ASSUMED, see README).
4. Fit battery tray (6× M6), electronics plates (12× M5), scanner pods (4× M6), collector bracket (2× M6), skirt standoffs (6, screwed in by the stud), coffee uprights (4× M6). Wire everything (48 V bus, scanners → PNOZ, CAN).
5. **Skirt** halves/segments over the base, 6× ISO 7380 M5 into the standoffs; bumper strip; fixed column cover SH02 (2 halves, M4 inserts) around the sleeve.
6. **Torso**: P02 onto the profile (M12×30 DIN 7984, 70 N·m), waist cover SH03 halves hung on P02 (4× M4). Lift the OpenArm body_link0 + arms (≈26 kg: two people or a hoist) onto P02, 8× M6×30 from below (8.4 N·m).
7. Post T-nuts: tray carrier P19 (4× M6), Gemini bracket + camera (2× M6, 2× M4 at 0.4 N·m); tray halves drop onto their pins.
8. Head: Insta360 mast foot + neck plate onto the top of body_link0 (4× M4×18 — ASSUMED holes), head shell (4× M4 into inserts), Insta360 on the 1/4"-20 stud.
9. Torso shell halves (around arms and post), coffee shelf on the uprights (4× M4 from below), coffee housing (3× M4 from below), machine + cups.
10. Commissioning: scanner field teach (contour learned at standstill), docking contact height check (140 mm), column index position recorded in software, payload test 2 × 4.1 kg.

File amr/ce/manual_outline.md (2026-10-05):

# Instructions for use - outline (MR Annex III 1.7.4, 3.6.3; EN ISO 3691-4 cl. 6; EN ISO 10218-2 info for use)

Language: Italian + language of each destination country (MR Art. 10(7)). Digital allowed (QR on robot, printable,
online >= 10 y, paper free on request within 1 month). **Safety information always on paper** if the robot can be used
by non-professional users (Art. 10(7)) - barista variant: assume yes.

1. **Identification** - manufacturer name/address/contact (1.7.4.2(a)), designation as on nameplate (b), DoC or URL/QR (c).
2. **Description and intended use** (d)(g) - variants C48 (certified arms) / OA (OpenArm R&D), autonomous mode, modes, payloads (2x3 kg + 2.1 kg tray),
   max speeds per mode, environment limits (indoor, slope, floor, temperature, IP), **forbidden uses** (h): outdoor, wet
   floor, climbing/sitting, direct hand-over from grippers, carrying people, towing, ATEX, unsupervised public use.
   ML/AI statement: what is autonomous, what is not safety-relevant; AI disclosure (AI Act Art. 50).
3. **Transport, handling, storage** (p)(o) - mass (total, base, removable parts, battery 14 kg each), lifting points,
   transport locks for arms, storage SoC and temperature for batteries, UN 38.3 shipping note.
4. **Site preparation and installation** (i)(o) - ISO 3691-4 cl. 6 site requirements: operating zones, aisle widths
   and clearances (>= 0.5 m, to fix), hazard zones and restricted zones, marking of floors, barriers at stairs/edges,
   no overhangs, lighting/glass surfaces, dock placement + 230 V supply with RCD, Wi-Fi coverage, map creation.
5. **Commissioning** (k) - field-set validation with test pieces (procedure + checklist), speed limits per zone,
   safety-parameter lock, acceptance record. Who may do it (trained person).
6. **Operation** (k)(f) - roles (supervisor per MR 3.2.4, operator, maintainer), start/stop/reset, modes and key
   selector, HMI and light/sound signals meaning, supervisory function (what it can command), docking/charging,
   barista operation, what to do when blocked.
   **Operating rules (rev B4, enforced partly by design, stated as instructions):**
   - speed bands 0.3 / 0.7 / 1.1 m/s (safe limits SLS[1] / SLS[2] / SMS in the drives); top speed 1.1 m/s = the speed at which the
     castor load rating is published (4 km/h);
   - acceleration / braking limits per speed band (scan plane ≤ 200 mm at the protective-field edge, SICK OI 8024596 p.40;
     `../CALC.md` §7b): 0.3 m/s band 1.36 / 0.79 m/s², 0.7 m/s 1.15 / 0.69, 1.1 m/s 0.97 / 0.61 m/s²
     (accel / decel), configured in the motion profile; do not raise them;
   - protective fields (SICK Safety Designer project, `../CALC.md` §7, incl. the ground-clearance supplement Z_F 150 mm):
     length from the scanner 401 / 613 / 943 mm, beyond each side 357 / 407 / 457 mm; rotate-in-place circle R 912 mm;
     arm-work field (OpenArm, base at standstill) circle R 2472 mm with 50 mm resolution (scan plane < 300 mm, SICK OI p.31);
   - rated room ambient **0…+35 °C** (the SWD drives are rated 0…+40 °C; their tunnels take room air from under the robot):
     keep the floor under the robot free of obstructions; stop at a fan-failure message;
   - floor: sharp thresholds ≤ 10 mm at any speed; thresholds 10-20 mm only bevelled ≤ 1:2 and crossed at ≤ 0.3 m/s;
     nothing higher (D80 castors; site survey before commissioning, slow zones in the map);
   - castor preload: set per corner on a scale (76 N, ±7 N) after any castor/spring service; check the scan plane with the
     test object at every field edge (184.5 ± 5 mm) after any scanner or castor work;
   - reverse travel is limited to <= 0.3 m/s by a permanent safe limit (SLSa) in the drives (SF5); no fast reversing;
   - never drive with the arms extended to the side or rear: arms in front of the body for work, parked for travel;
   - rotate on the spot only with the arms parked (SF4/SF8);
   - objects and drinks travel in the tray, never in the hands (SF8; hand-over only via the tray with OpenArm).
   - Q0 (ED250B-L key disconnect) is an emergency / no-load isolator: switch it only with K0 open (robot in SERVICE or off);
   - the batteries stop the robot at 48 V (application cut-off K0V); dock before that; never let the packs reach the 40 V BMS
     lock-out (manual ON needed); packs within 50 mV at >= 95 % SoC before connecting them in parallel (service);
   - dock charger NPB-750-48: DIP 2 OFF / 3 ON ("flooded", 56.8 / 53.6 V); never the 58.4 V LiFePO4 preset;
   - fans are required (S24 converter max 50 C): replace filters at the interval, an over-temperature alarm parks the robot.
7. **Safety** (l)(m) - safety functions summary: SF1-SF16 (as in `../electrical/SAFETY_FUNCTIONS.md` rev B2, Pilz
   PNOZmulti 2) + SF17 supervisory watchdog, stopping distances table per speed, daily checks
   (E-stop test, field test, warning devices, scanner windows clean), **residual risks** (RISK_ASSESSMENT.md §4),
   PPE for maintainers, laser class 1 statement, RF/implant information (w), noise values (u).
8. **Maintenance and cleaning** (r)(s)(t) - LOTO via key service disconnect, wait time for capacitors, intervals
   (brakes, castors, scanner windows, fan filters, coffee descaling), food-contact cleaning (2.1),
   spare parts affecting safety (scanners, E-stops, brakes, batteries: originals only), safety-function proof tests,
   SW updates (signed, versions log; 1.1.9).
9. **Faults and emergencies** (q)(v) - error codes, releasing a trapped person (manual brake release procedure for
   ez-Wheel; push robot), battery fire (extinguisher type, evacuation), arm stuck.
10. **Decommissioning/disposal** - battery removal, Battery Reg. take-back, WEEE.
11. **Technical data** - nominal power kW, mass, dimensions, swept radius when rotating in place (~440 mm with arms parked), speeds (forward 1.1 m/s max, bands 0.3 / 0.7 / 1.1 m/s, reverse 0.3 m/s max), rated ambient 0…+35 °C,
    battery, charging, radio bands/power, noise, IP, vibration N/A.
12. **Annexes** - DoC copy, wiring overview, field-set drawings, cybersecurity guidance (EN 18031: passwords, network
    setup, update policy, support period, vulnerability contact for CRA).

## Marking / labels
**Nameplate (base, visible, indelible)** - MR Art. 10(5)(6), Annex III 1.7.3, 3.6.2:
- CE marking (Art. 24; >= 5 mm)
- Manufacturer name, registered trade name/mark, postal address, website/e-mail
- Designation: "Giorgio - autonomous mobile service robot", model/type, serial number, year of construction
- Nominal power (kW) [3.6.2(1)(a)], mass of the most usual configuration (kg) [3.6.2(1)(b)]
- Nominal voltage 48 V DC (51.2 V nom., 40-58.4 V), battery type LFP 2 x 1.54 kWh
- Max payload (2 x 3 kg + 2.1 kg tray), IP rating
- QR code / URL to digital instructions and DoC (Art. 10(7)(a), 10(8))
**Other labels**: battery labels per Reg. 2023/1542 Art. 13 (from Discover) + crossed-out bin; WEEE bin symbol;
ISO 7010 pictograms: W019 crushing (rotation in place / dock), W017 hot surface (coffee), W012 electricity (battery bay), M002 read
manual, P "do not climb/sit"; "Laser class 1" (if supplier requires); E-stop yellow background; key disconnect
label; mass on removable heavy parts (battery packs 14 kg) per 1.7.3; dock: own nameplate + CE + 230 V data.

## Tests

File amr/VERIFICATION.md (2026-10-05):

# AMR rev B: verification of purchased components against public documentation (2026-10-05)

Owner requirement: the design must be about 99 % certain from published information, with nothing that depends on asking a supplier.
This file takes every open supplier question (`electrical/ELECTRICAL.md` §14, `README.md` "Before pre-production", `ce/GAPS.md` G2/G3/G8)
and every ASSUMED input about a purchased component (`CALC.md`, `electrical/netlist_amr.yaml`), and tries to close it from official
manufacturer documents.

**Status rules**
- **CLOSED:** a verbatim quote from an official manufacturer document answers the question.
- **REPLACE:** the document does not answer the question, so a specific alternative is proposed whose datasheet does.
- **RESIDUAL:** the item cannot be documented publicly at all (price, physical value to be measured, no published claim). The table says why it does not affect design safety.

PDFs are saved in `../docs/fonti/` (34 MB). Large manuals are kept as page extracts and cited by URL.
Page numbers are PDF pages unless the document prints its own page numbers (ez-Wheel "Page x on 132", Pilz, SICK).

This file only reports. **No design file was changed:** `amr_cad.py`, `amr_params.py`, `electrical/*` and the BOM are untouched. The
required changes are listed at the end.

## Summary

| Group | Rows | CLOSED | REPLACE | RESIDUAL |
|---|---|---|---|---|
| ez-Wheel SWD 125 | 14 | 9 | 1 | 4 |
| Discover battery + LYNK II | 15 | 12 | 0 | 3 |
| Mean Well converters + charger | 14 | 12 | 2 | 0 |
| Roboteq RoboPad | 6 | 5 | 1 | 0 |
| SICK nanoScan3 Pro I/O | 11 | 10 | 1 | 0 |
| Pilz PNOZmulti 2 + PSEN | 17 | 14 | 1 | 2 |
| Siemens / Albright / Finder / maxon / PEAK / E-stop / castors | 13 | 11 | 2 | 0 |
| Outside the base package (prices, arms) | 3 | 0 | 0 | 3 |
| **Total** | **93** | **73** | **8** | **12** |

**What the 12 RESIDUAL items are:**
- **2 price rows.**
- **4 physical values to measure in the type tests:** SWD brake torque, drive reaction time, regen chopper, peak-torque duration.
- **3 battery data with no published claim:** prospective short-circuit current, vibration rating, BMS PL.
- **The PNOZ timer element**, which can be checked in the free Configurator.
- **Arm data** (Kassow, OpenArm), which is outside the base.

None of them needs a supplier answer for the base to be safe, provided the design changes at the end are applied.

**Findings the earlier rev B documents had wrong:**
- The DDR-480 and DRDN40 must not be mounted lying flat.
- The DDR remote input is the opposite logic of what was assumed.
- The LYNK II "alarm NC = OK" wiring is not fail-safe.
- The SWD has no safety-rated SS1, and its default "brake" is a motor phase short.
- The PNOZ logic time is 33–54 ms, not 10 ms.
- No catalogue D100 spring castor has a spring soft enough for the 31 N/mm window.
- RoboPad has no wireless CAN and requires ≤ 60 V under fault conditions.
- The PNOZmulti Configurator is free.
- 3RT2026 with 2 poles in series is rated 35 A DC-1 at 60 V. This is good news: the "thin" margin is resolved.

## Verification table

| ID | Question | Answer | Verbatim quote | Source (+page) | Status | Note / impact |
|---|---|---|---|---|---|---|
| E1 | SWD 125 accepts a regulated 24 V DC-DC (no battery) on T24? | Yes as far as the interface is specified: the supply is defined only by voltage/current thresholds (UV alert 16 V / error 14 V, OV alert 32 V / error 34 V, OC alert 25 A / error 30 A); no battery is required anywhere. BUT the internal phase-short brake is disabled when the source "no longer accepts input current" (FW ≥ 1.1.4), so T24 must be able to sink regen current: the DSR 50/5 clamp (27 V < 32 V alert) provides that. | "Under-voltage Alert 16 Volts 1000 ms … Error 14 Volts … Over-voltage Alert 32 Volts 1000 ms … Error 34 Volts … Over-current Alert 25 Amps 1000 ms … Error 30 Amps" (§8.1) and "Incorporation of an overvoltage protection mechanism … when a power source used to store energy is no longer connected or no longer accepts input current … the motor will not apply internal braking" (Release note FW 1.1.4) | SWD user manual v2.0.2 p.34, p.124 | CLOSED (interface) | Design rule: T24 sink path (DSR 50/5 clamp at 27 V) is mandatory, not optional; keep clamp < 32 V. Regen energy is bounded by robot kinetic energy (½·164·1.5² = 185 J total), a physics bound, so no ez-Wheel figure is needed. |
| E2 | Internal regen chopper / brake resistor in the SWD? | Not documented (manual never mentions a chopper). Design does not rely on one: external clamp absorbs everything. | – (absence) | SWD manual v2.0.2 (whole document searched: "regen", "chopper", "dissipat") | RESIDUAL | Not safety-relevant once E1 design rule is applied; verified by TP-03/TP-14 worst-case regen test. |
| E3 | Parking-brake holding torque (EW2A-125HN04**B**) | Not published. Datasheet only lists "Option(s) Parking brake" and mass 7 kg with brake; manual: "Consult ez-Wheel for a brake compatible with your product." The default SBC on STO is the INTERNAL brake = motor phase short-circuit (dynamic, held ~3 min after power loss), not a friction brake. | "Internal braking works by short-circuiting the motor phases. While the external brake works by lack of current." / "By default, the 'SBC command 3' braking mode is activated on an STO signal, i.e., internal motor braking." / "Brake hold time is approximately three minutes." | SWD manual v2.0.2 p.24, p.106-107; datasheet EW2A-125HN04x 07/2024 | RESIDUAL (measure) | Design must not use a brake-torque value: protective fields are sized on SS1-t with the documented motor peak torque (13 Nm → max 2.5 m/s² at 164 kg ≥ 1.5 m/s² ramp). Cat-0 stopping distance (power loss) and slope holding (6 %: 0.83 Nm per motor needed) become type-test items (ISO 3691-4 brake test). |
| E4 | SS1 stop ramp inside the drive (1.5 m/s²) | The drive has NO safety-rated SS1 (manual v2.0.2 safety list: STO, SBC, SBU, SDI, SLS, SLSa, SMS; catalogue shows SS1 with an "UNDER DEVELOPMENT" stamp). The ramp is the non-safe CiA 402 quick-stop/deceleration ramp (604Ah/6049h). The rev B design already uses SS1-t (PNOZ timer) - consistent. | "There are 3 ramp configurations: … A fast deceleration ramp" (§ Ramps) ; safety summary table lists no SS1 | SWD manual p.79-80, p.87-90; catalogue 02/2025 p.43 | CLOSED | Check: PNOZ STO delay 0.5 s < 1.0 s needed to ramp from 1.5 m/s at 1.5 m/s² → at speeds > 0.75 m/s STO arrives mid-ramp and the rest is a cat-0 (phase-short) stop. Either set the delay ≥ 1.1 s or keep it and size the fields on the cat-0 tail (see E3). |
| E5 | PFHd / MTTFd / Cat per safety function; SISTEMA library | Published: STO via STO1/STO2 Cat 4 PL e PFHd 1.42E-9; SLS/SLSa/SDI via pair of SafeInputs Cat 3 PL d PFHd 2.29E-7; SBC3 internal via STO inputs PFHd 2.29E-7 (PL d); MTTFd 14 years for SWD 125. No SISTEMA library needed: enter the subsystem PFHd directly. | "Safe Torque Off (STO) STO1 et STO2 inputs Category 4 PL e 1,42E-9 SIL 3" … "Safely limited speed (SLS) Pair of SafeInput Category 3 PL d 2,29E-7" … "A 14-year MTTFD is used for SWD®-Core & SWD®-125" | SWD manual v2.0.2 p.89-90 | CLOSED | Use 2.29E-7 for SLS/SLSa: it consumes most of the PL d budget (< 1E-6) — total SF chain with scanner (PFHd ~ 8E-8 class) + PNOZ still < 1E-6. |
| E6 | Test-pulse tolerance of STO/INSafe inputs | Not quantified. The manual only states OSSD compatibility ("Safety Inputs, OSSDs compliant"; "Activation of STO by OSSD outputs, compliance up to SIL3 / PLe … a safety controller"). No pulse width/period limit given. | "Activation of STO by OSSD outputs, compliance up to SIL3 / PLe." / "A certified sensor with a pair of OSSDs, a sensor, a safety controller." | SWD manual v2.0.2 p.15, p.100 | REPLACE | Drive STO1/STO2 and INSafe from positive-guided relay contacts (no test pulses), see Pilz row for the relay expansion; or accept OSSD-compliant claim + TP test. See consolidated changes. |
| E7 | SLSa as a permanent function, asymmetric thresholds, mirrored wheels | Yes: any safety command can be mapped permanently (2624h/2625h); SLSa has separate positive and negative limits (3052h/3055h); polarity 607Eh does NOT change the safety sign convention, so each wheel is configured with its own sign (left wheel: forward = negative). SLSa is guaranteed only ≥ 100 rpm motor (0.3 m/s → ~167 rpm motor: OK). | "It is possible to permanently activate a safety function. To do this, map the safety function you wish to activate permanently to one of the two sub-objects: 2624h…" / "SLSa positive velocity limit u32 … SLSa negative velocity limit u32" / "The 'polarity' object has no impact on the positive direction of rotation used for the SDIp and SDIn safety" / "The SLSa safety function is guaranteed from 100 rpm … at the motor shaft." | SWD manual p.93, p.111, p.76 | CLOSED | Per-drive parameter sets (L ≠ R) must be documented with their configuration signatures (3058h). |
| E8 | SBU (push mode) mapped to an INSafe input | Yes: INSafe_1…4 commands are freely mappable (2620h sub 03-06, RW) and SBU is "activated by a signal on a safety input"; only in SWITCHED_ON_DISABLED / READY_TO_SWITCH_ON. | "This mode can be activated by a signal on a safety input of the SWD® or by reception of a safety message on the CANopen safety bus." | SWD manual p.94-95, p.107 | CLOSED | – |
| E9 | STO/brake reaction time of the drive (20 ms ASSUMED) | Not published as a number; manual gives only the SFRT summation method. | "To determine the worst-case SFRT of any SR control loop, the user must sum all the worst-case safety reaction times of each subsystem" | SWD manual p.121-122 | RESIDUAL (measure) | Measure SFRT in TP (scanner OSSD → torque off) and add ≥ 2× margin; with field sizing at 1.5 m/s each extra 10 ms = +15 mm. Not a supplier dependency once measured. |
| E10 | Peak torque duration (13 Nm) | Not published. Indirect limit: supply OC alert 25 A after 1000 ms, error 30 A immediately. | "Over-current Alert 25 Amps 1000 ms … Error 30 Amps -" | SWD manual p.34 | RESIDUAL | Not safety-relevant (traction performance). Design accelerations (1.5 m/s²) need ~5.1 Nm per wheel ≤ 7.9 Nm nominal. |
| E11 | Load rating vs speed | 250 kg static, 200 kg at 6 km/h, 150 kg at 9 km/h per wheel. At 1.5 m/s (5.4 km/h) the drive-wheel load (≤ ~60 kg each) is far below 200 kg. | "250 kg (static) 200 kg at 6 km/h 150 kg at 9 km/h 100 kg at 11 km/h" | EW2A-125HN04x datasheet 07/2024 | CLOSED | Also: "Indicative lifespan* 5 000 h / 1 500 000 starts/stops" → service-life item for the maintenance plan (17 h/day ≈ 1 year). |
| E12 | STO hold beyond 100 h | STO state guaranteed only 100 h; beyond that an external safety relay/controller with rearming is required (our PNOZ provides it). | "The performance levels of the safety functions and the STO position guarantee are guaranteed for a period of 100 hours." | SWD manual p.98 | CLOSED | Already satisfied (PNOZ drives STO + reset). |
| E13 | Vendor 3D CAD | Available after free registration on ez-wheel.com (no supplier contact needed); manual gives overall dimensions (L 181 / 196 mm with brake, G 111 mm). | "Gearbox Dim 'G' ± 0.3 … 111 … Dim 'L' ± 2 … 181 … 196 (with external brake) … Weight 6.2 / 7" | SWD manual p.28; product page "Download 3D CAD file" | CLOSED | Download STEP with a free account and re-run the interference check. |
| E14 | Supply connector / cable | M12 L-coded 5-pin, 2×16 A pins; Phoenix SAC-5P-M12MSL/1,5-280 FE SH 1414884 named; ≤ 5 m from source recommended. | "Phoenix Contact SAC-5P-M12MSL/ 1,5-280 FE SH – 1414884, 1.5m" / "A maximum length of five meters between the power source and the SWD® is recommended." | SWD manual p.22 | CLOSED | – |
| D1 | Discover DLP-GC2-48V: may the pack lie flat? | Yes. Only upside down is forbidden. Keep ≥ 50 mm free above the top cover and use hold-downs. | "4. Proper orientation. Do not install upside down." / "Maintain at least 50 mm (2 in) above the top cover for open airflow." / "Secure the battery or battery box with over-the-top-hold-downs or a bracket" | DLP-GC2 Installation & Operation Manual 805-0027 Rev N §9.2 p.10 | CLOSED | CAD: ≥ 50 mm free in front of the top cover of each lying pack. Closes G8 (orientation). |
| D2 | Parallel operation of 2 packs | Allowed, up to 20 packs. Conditions: same model, packs within 50 mV at ≥ 95 % SoC, equal cable gauge and length, LYNK network. | "The maximum number of batteries that can be installed in a parallel configuration is 20." / "within 50 mV (0.05 V) of each other, at 95% SOC or higher" / "Equal cable gauge… Equal cable length." | 805-0027 §3.6 p.5, §9.7 p.12–13 | CLOSED | H01 = H02 in length and gauge. Add the 50 mV check to the commissioning procedure. |
| D3 | Pre-charge / inrush | The pack pre-charges up to 23 mF of load capacitance before its own relay closes. K0 later closes onto a live bus, so K0P stays. | "The battery is equipped with a Pre-charge System that will energize external capacitive loads before turning on the main relay." / "Maximum Load Input Capacitance … 23 mF" | 805-0027 §7.3.2 p.8, Table 3-1 p.4 | CLOSED | – |
| D4 | LYNK II alarm relay: contact type and rating | Relay 1 is NO/NC/COM; relays 2 and 3 are NO. Rating 0–30 V DC, 5 A max; no inductive rating is given. The NC contact is closed when the relay is de-energised, so "NC closed = OK" is **not fail-safe**. Triggers are SoC, current, cell voltage and cell temperature. | "The relays allow 0 to 30 VDC at a maximum of 5 A to pass through" / "Pin 11 allows voltage to pass through when Relay 1 is deactivated." | LYNK II Relay Guide §3.1 p.6, §4.1 p.7 | CLOSED (rating) | **Design change:** use a NO contact programmed "energised = OK", with freewheel diodes on the K0/K0P/K0T coils. The 1.5 A coil load is below 5 A. |
| D5 | Internal fuse | 60 A, 58 V DC, Littelfuse 142.5631.5602 | "Fuse … 58 V 60 A" / "142.5631.5602 60A,58VDC" | 805-0027 p.4, §12 p.17 | CLOSED | Each pack cable is protected by a documented 60 A fuse. |
| D6 | Prospective short-circuit current | Not published: the "Short Circuit" field on the product page is empty. | product page spec field "Short Circuit" (no value) | discoverbattery.com/products/search/dlp-gc2-48v (saved .txt) | RESIDUAL | Bounded by design: choose every fuse and switch on B48 with documented DC breaking ≥ 20 kA (F0 3NA3830: 25 kA, SI5; 10×38 gPV links: check ≥ 20 kA). The 60 A internal fuses limit the pack contribution. No supplier figure is then needed. |
| D7 | Charge voltages | Bulk 56.8 V, absorption 55.2 V, float 53.6 V, termination 0.75 A | "Fast Charge - Bulk Vdc - U1 … 56.8 V" / "Float Vdc - U3 … 53.6 V" / "Charge Termination Current … 0.75 A" | 805-0027 Table 3-1 p.4 | CLOSED | Matches the plan. |
| D8 | Maximum charge current (30 A ASSUMED) | Per pack: 29 A for 1 h, 15 A continuous. Pair: 58 A / 30 A. The design's 11.1 A per pack passes. | "Max Charge Current (1 hour) … 29 A"; "Max Continuous Charge Current b … 15 A"; "2 Batteries … 58 A … 30 A" | 805-0027 p.4–5 | CLOSED | Replace the ASSUMED value in CALC with 15 A continuous per pack. |
| D9 | Discharge ratings | Per pack: 58 A for 1 h, 15 A continuous over repeated cycles, 90 A peak (10 s in the manual, 3 s on the web page). The BMS trips at > 58 A for 10 s. | "Max Discharge Current (1 hour) 58 A"; "Max Continuous Discharge Current b 15 A"; "> 58 A for 10 s"; "90 A RMS (3 sec)" | 805-0027 p.4–5; product page | CLOSED | "116 A continuous" in ELECTRICAL §3 is a 1-hour rating; the pair's repeated-cycle continuous rating is 30 A. The average draw is ~4 A, so this passes, but correct the text. |
| D10 | BMS low-voltage cut-off (40 V ASSUMED) | The BMS disconnects at < 40 V for 5.2 s and then needs a manual ON. Discover recommends the application cut off at ≥ 48 V. | "Low Voltage Disconnect Recommended … 48.0 V" / "Low Voltage Disconnect … 40.0 V" / "Program the low voltage cut-off … at or above the Low Voltage Disconnect Recommended values" | 805-0027 Table 3-1 p.4, §10.1 p.14 | CLOSED | **Design change:** add a 48 V application LVCO (a LYNK relay or the Jetson opens K0). Runtime figures fall slightly (usable energy above 48 V). |
| D11 | Current share between packs (0.55 ASSUMED) | No sharing factor is published. The pair ratings are linear and the system is balanced over LYNK. | "all battery cells are balanced as an entire system" / "Linear scaling of charge, discharge and peak capacity" | 805-0027 §7.3.4 p.8; product page | CLOSED (superseded) | Use the published pair ratings (Table 3-9) instead of a share factor. |
| D12 | Vibration rating | Not published. The certificates are UN 38.3, IEC 62619, UL 2271 and CE; the CE DoC covers EMC and RoHS only. | "UN38.3 Transportation / IEC 62619 / UL 2271 … / CE" | 805-0027 p.5; CB cert DK-142118-A1-UL; EU DoC 830-0047 | RESIDUAL | Indoor AMR on industrial floors; UN 38.3 includes a transport vibration test. Use hold-downs plus a prototype vibration/bump test (TP). |
| D13 | BMS functional-safety evidence for SF12 | No SIL or PL claim is published. The evidence is IEC 62619:2022 (CB certificate) and UL 2271. The BMS switches with a main **relay**, not FETs. | "IEC 62619:2022 … Additionally evaluated to: EN IEC 62619:2022"; "The main relay is ON (Closed)" | CB cert p.1; 805-0027 §6 p.7 | RESIDUAL | Argue SF12 as a product-standard function (IEC 62619) plus independent layers: F0, charger CV preset (M11), 48 V LVCO (D10), dock OV relay (M12). No PL credit is taken for the BMS. Correct "BMS FETs" to "BMS main relay". |
| D14 | Load dump / motor on the bus | A BMS trip causes a load-dump spike. Discover warns against motor voltage-clamp systems directly on the battery; our clamps sit on T24 behind the DC-DCs. | "Disconnection will result in a voltage spike (Load Dump)" / "external motor voltage clamping systems … may result in damage" | 805-0027 p.5; product page | CLOSED | B48 loads must tolerate > 60 V; the DDR-C input goes to 67.2 V (M6). |
| D15 | LYNK II gateway: certification, supply, size | CE, IP20 indoor, −20…50 °C, 13–90 V input, 120 × 135 × 44 mm. Power draw is not published (minor). | "Marking CE"; "IP20 (Indoor Use Only)"; "13 - 90 V"; "LxWxH 120 x 135 x 44 mm" | LYNK II motive sell sheet 885-0035 p.2 | CLOSED | CAD E38 (65 × 70 × 30 ASSUMED) is too small: use 120 × 135 × 44. |
| M1 | DDR-480C-24 derating when lying flat (E50) | **Not allowed.** Only vertical mounting with the input terminals at the bottom; clearances 5 mm left/right, 40 mm above, 20 mm below. The DRDN40 has the same rule. | "The appropriate mounting orientation for the unit is vertical, the input terminals at the bottom … such as upside down, horizontal, or table-top mounting, is not allowed." / "5mm left and right, 40mm above and 20mm below" | Mean Well DDR-120/240/480 Installation Manual p.2; DRDN20/40 manual (URL) | CLOSED | **Design change:** E50/E52 go on vertical rails (centre-bay spine faces). The "raise P11 by 3 mm" note is no longer needed. |
| M2 | DDR remote ON/OFF from a dry contact (K0 aux) | Possible on TB1, but **open = ON, short = OFF**, so the converter needs a K0 **NC** auxiliary contact. | "Open or 5.5 ~ 10VDC power supply ON … Short or 0 ~ 0.8VDC power supply OFF" | DDR-480-SPEC p.4 | CLOSED | Netlist change only. SW80 aux contact: check NO/NC availability in the A-suffix code (Albright data sheet). |
| M3 | DDR-480C-24 efficiency (0.93 ASSUMED) | 92 % typical | "EFFICIENCY (Typ.) … 92%" | DDR-480-SPEC p.2 | CLOSED | CALC: 0.93 → 0.92. |
| M4 | Parallel current sharing | Up to 4 units; total ≤ rated × N × 0.9 (36 A for 2); outputs matched within 0.2 V | "(The rated current per unit) x (Number of unit) x 0.9" / "4 units is the maximum" | DDR-480-SPEC p.4 | CLOSED | T24 continuous capacity is 36 A; the 54 A shared peak is an extrapolation of the 150 % / 5 s rating. |
| M5 | OVP latch / reverse current | OVP at 28.8–35 V, latching; DRDN reverse current ≤ 1 mA | "28.8 ~ 35V … Shut down o/p voltage, re-power on to recover"; "INPUT REVERSE CURRENT (max.) 1mA" | DDR-480-SPEC p.2; DRDN40-SPEC p.2 | CLOSED | A 27 V clamp is below the minimum OVP (28.8 V) and below the SWD OV alert (32 V): consistent. |
| M6 | Input range and low-voltage derating | 33.6–67.2 V; output derates below 43.2 V (≈ 97 % at 40 V); 60 °C maximum ambient | "33.6 ~ 67.2Vdc"; derating curve "C Type: 33.6 … 43.2"; "60°C for DDR-480 series" | DDR-480-SPEC p.2–3; installation manual | CLOSED | With the 48 V LVCO (D10) the derating zone is never reached. |
| M7 | DDR-240C-24 (S24) | 10 A, 360 W for 3 s, 40 mm wide, 50 °C maximum ambient | "10A"; "360W (3sec.)"; "50°C for DDR-240 series" | DDR-240-SPEC p.2; installation manual | CLOSED | The 45 °C bay leaves a thin margin, so the fans are safety-relevant for S24. Mount vertically (M1 rule). |
| M8 | DDR-120C-12 (U5) | 10 A, 15 A for 3 s, 32 mm wide, 55 °C maximum | "10A … 15A … 180W (3sec.)"; "55°C for DDR-120" | DDR-120-SPEC p.2 | CLOSED | – |
| M9 | DDR-60L-5 (U6) | 12 A, 18–75 V input, 52.5 × 90 × 54.5 mm | "12A"; "18 ~ 75Vdc"; "52.5*90*54.5mm" | DDR-60-SPEC | CLOSED | CAD E58: width 40 → 52.5 mm. |
| M10 | DRDN40-24 / -48 | 40 A per input, 60 A for 5 s; 48 V version 36–60 V, reverse 65 V. Bridging the two inputs is not a documented use. | "0~40A per input"; "60A, 5Sec."; "36~60Vdc"; "65Vdc"; "3. Single Use" | DRDN40-SPEC p.2, p.4 | CLOSED | Dock U8: use a single input (40 A ≥ 25 A charge). |
| M11 | NPB-1700-48: setpoints, CAN, certification | CV 42–80 V; the DIP preset "flooded" gives exactly 56.8 / 53.6 V at 25 A, so no reprogramming is needed. CANBus 2.0B; IEC 60335-2-29. | "Pre-defined, flooded battery 56.8 … 53.6"; "25A"; "CANBus 2.0B"; "IEC60335-1/2-29" | NPB-1700-SPEC p.2, p.5 | CLOSED | Set DIP 2 = OFF, 3 = ON. Never use the 58.4 V "LiFePO4" preset. The ACTION "reprogram the charger" becomes "set the DIP". |
| M12 | Charger overvoltage vs RoboPad 60 V limit | **Conflict:** the NPB OVP trips only at 82–100 V, but RoboPad requires ≤ 60 V even under fault conditions. | "OVER VOLTAGE … 82 ~ 100V" / "shall ensure that the voltage does not exceed 60 V DC even under fault conditions." | NPB-1700-SPEC p.2; RoboPad datasheet v1.3 p.7 | REPLACE (add part) | Add a DIN overvoltage-monitoring relay set at 59 V, opening the dock DC contactor (e.g. a Finder 71-series class DC voltage monitor; pick one whose datasheet covers 60 V DC). ~€60–90 per dock; station side only, no robot change. |
| M13 | Charger EMC class vs RoboPad conditions | RoboPad requires a charger compliant with EN 61000-6-3; NPB-1700 radiated emission is Class A. | "independently compliant with IEC/EN 61000-6-1 and IEC/EN 61000-6-3"; "Radiated … Class A" | RoboPad v1.3 p.14; NPB-1700-SPEC p.2 | REPLACE (option) | Option A: **NPB-750-48** (Class B, IEC 60335-2-29, same flooded preset, 11.3 A): −€100, but 20→90 % takes ≈ 5 h instead of 1.9 h. Option B: keep NPB-1700 and pass a dock-level EMC test (TP-19). |
| M14 | Charger vs battery capacity | Mean Well defers to the battery maker; Discover allows 58 A (1 h) / 30 A continuous for the pair. | "consult your battery manufacturer" | NPB-1700-SPEC p.2; 805-0027 | CLOSED | 25 A ≤ 30 A. |
| R1 | RoboPad current | 60 A continuous; 75 A only at 80 s on / 60 s off; 60 V max; 0–40 °C | "Continuous Current 60 A"; "Current 80 sec on/60 sec off 75A"; "Voltage 60V max" | RoboPad datasheet v1.3 p.15 | CLOSED | Correct 75 A → 60 A continuous. The 25 A charge passes. |
| R2 | Part number | The collector is RPCOL90-100, not RPCOL90C-100. | "RPCOL90-100 RoboPad Extendable Collector, 90mm wide, 100A" | v1.3 p.2 | CLOSED | Fix BOM and netlist. |
| R3 | Alignment tolerance | ±5 mm left/right; 10 mm extension range. Fore/aft tolerance is not stated. | "Left/Right alignment tolerance +/–5mm"; "Extension range 10mm" | v1.3 p.15 | CLOSED | Fore/aft is taken up by the spring extension; the pads stay dead until docking is confirmed. Verify in TP. |
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

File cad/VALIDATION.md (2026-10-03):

# Giorgio CAD — validation report

Generated by `cad/validate.py` (2026-10-03 13:35, 219 s). Units mm / kg / N. Frame: robot base (x forward, y left, z up, origin on the floor at the Tracer centre). 67 parts, 99 bolted joints.

**Summary: 55 PASS, 17 WARN, 0 FAIL.** WARN = passes the hard limit but not the target margin, or depends on an ASSUMED interface.

| Section | Check | Result | Numbers |
|---|---|---|---|
| Model | all B-rep solids valid | **PASS** | 230 solids, invalid: [] |
| Fasteners | hole alignment (coaxial, parallel, contiguous stack) | **PASS** | 99 bolts; worst threaded-hole axis offset 0.000 mm, worst angle 0.00 deg, worst stack gap 0.00 mm |
| Fasteners | hole sizes per ISO 273 / ISO 2306 tap drill / insert spec | **PASS** | clearance holes medium series unless noted; tapped = d - P; inserts Kerb Konus 860 |
| Fasteners | thread engagement / no bottoming | **PASS** | min Le/req ratio 1.00; failing: [] |
| Fasteners | edge distance / wall around holes | **PASS** | 156 holes checked; e >= 1.2 d0 (EN 1999-1-1 min) in metal, insert wall per Kerb Konus in PA12; failing: [] |
| Interference | static assembly (lift 0, shuttle out), all part pairs | **PASS** | 633 bbox-overlapping pairs checked with exact OCC boolean; 0 overlaps > 0.1 cm3 (0.005 cm3 for fasteners); 1 minor/touching |
| Interference | coffee shuttle under the spout (fixed column) | **PASS** | 312 pairs; 0 overlaps |
| Interference | coffee shuttle at mid stroke | **PASS** | 0 overlaps |
| Clearance | shuttle stroke (140 mm) vs machine/housing/shelf/actuator | **PASS** | min clearance 2.0 mm (P24_shuttle_cup_carrier vs S07_coffee_machine_inissia_EN80 at +80 mm); guide rail contact excluded |
| Arm sweep | arms vs P26_cup_stack_holder | **WARN** | min clearance 2.4 mm (openarm_right_ee_outer_finger @ rec_caffe_sh069#582); poses in contact: 0/793 |
| Arm sweep | arms vs S05_orbbec_gemini_336L | **WARN** | min clearance 3.1 mm (openarm_right_ee_base_link @ logistica_v9#26); poses in contact: 0/793 |
| Arm sweep | arms vs S07_coffee_machine_inissia_EN80 | **WARN** | min clearance 4.4 mm (openarm_right_ee_inner_finger @ rec_caffe_sh069#529); poses in contact: 0/793; 3 poses with the intended finger contact on the machine top (button press) excluded |
| Arm sweep | arms vs SH03_waist_cover | **PASS** | min clearance 7.0 mm (openarm_right_ee_base_link @ home#792); poses in contact: 0/793 |
| Arm sweep | arms vs OA_body_link0(STL) | **PASS** | min clearance 10.3 mm (openarm_right_link2 @ rec_caffe_sh069#699); poses in contact: 0/793 |
| Arm sweep | arms vs SH04a_torso_shell_front | **PASS** | min clearance 10.8 mm (openarm_left_ee_inner_finger @ logistica_v9#230); poses in contact: 0/793 |
| Arm sweep | arms vs SH04b_torso_shell_rear | **PASS** | min clearance 12.6 mm (openarm_right_link2 @ logistica_v9#93); poses in contact: 0/793 |
| Arm sweep | arms vs P17_insta360_mast | **PASS** | min clearance 13.3 mm (openarm_left_base_link @ logistica_v9#28); poses in contact: 0/793 |
| Arm sweep | arms vs SH05_head_shell | **PASS** | min clearance 13.5 mm (openarm_left_base_link @ logistica_v9#28); poses in contact: 0/793 |
| Arm sweep | arms vs P28_torso_shell_bracket_rear | **PASS** | min clearance 13.6 mm (openarm_left_base_link @ logistica_v9#80); poses in contact: 0/793 |
| Arm sweep | arms vs P20_tray_half_R | **PASS** | min clearance 13.9 mm (openarm_right_ee_inner_finger @ logistica_v9#63); poses in contact: 0/793 |
| Arm sweep | arms vs P24_shuttle_cup_carrier | **PASS** | min clearance 17.7 mm (openarm_right_ee_outer_finger @ rec_caffe_sh069#585); poses in contact: 0/793 |
| Arm sweep | arms vs P18_gemini_bracket | **PASS** | min clearance 20.7 mm (openarm_left_base_link @ logistica_v9#80); poses in contact: 0/793 |
| Arm sweep | arms vs P20_tray_half_L | **PASS** | min clearance 25.8 mm (openarm_left_ee_inner_finger @ logistica_v9#39); poses in contact: 0/793 |
| Arm sweep | arms vs SH06_coffee_housing | **PASS** | min clearance 26.6 mm (openarm_right_ee_inner_finger @ rec_caffe_sh069#534); poses in contact: 0/793 |
| Arm sweep | arms vs P19_tray_carrier | **PASS** | min clearance 47.5 mm (openarm_right_link5 @ home#792); poses in contact: 0/793 |
| Arm sweep | arms vs P21_coffee_shelf | **PASS** | min clearance 61.2 mm (openarm_right_ee_outer_finger @ rec_caffe_sh069#585); poses in contact: 0/793 |
| Arm sweep | arms vs P27_torso_shell_bracket_front | **PASS** | min clearance 73.2 mm (openarm_left_ee_inner_finger @ logistica_v9#232); poses in contact: 0/793 |
| Arm sweep | arms vs S04_insta360_X4 | **PASS** | min clearance 116.4 mm (openarm_right_link4 @ logistica_v9#162); poses in contact: 0/793 |
| Arm sweep | arms vs SH02_column_cover_fixed | **PASS** | min clearance 157.8 mm (openarm_right_ee_inner_finger @ home#792); poses in contact: 0/793 |
| Arm sweep | arms vs SH01_deck_cover | **PASS** | min clearance 296.1 mm (openarm_right_ee_inner_finger @ home#792); poses in contact: 0/793 |
| Arm sweep | arms vs S02_nanoScan3_1 | **PASS** | min clearance 544.6 mm (openarm_left_ee_outer_finger @ home#792); poses in contact: 0/793 |
| Arm sweep | arms vs S02_nanoScan3_0 | **PASS** | min clearance 545.8 mm (openarm_right_ee_outer_finger @ home#792); poses in contact: 0/793 |
| Covers | OpenArm body_link0 base plate (250x190 at z 580-588) inside the waist cover | **PASS** | 100.0% of 1500 sampled STL vertices covered |
| Covers | OpenArm body_link0 top (z 1310-1353, |y|<=68) inside torso shell / under neck plate | **PASS** | 100.0% of 1500 sampled STL vertices covered |
| Footprint | upper body + arms (home) inside the Ranger Air plan (552 x 500) | **WARN** | overhanging parts (mm2 outside): [('P21_coffee_shelf', 34292), ('SH06_coffee_housing', 17142), ('P24_shuttle_cup_carrier', 6060), ('P19_tray_carrier', 3864), ('S10_actuonix_P16_150', 3740), ('P20_tray_half_R', 3549), ('P20_tray_half_L', 3549), ('P26_cup_stack_holder', 3414)] |
| Docking | rear dock-contact zone free (x < -276, |y| <= 90, z <= 300): AgileX brush plate reachable | **PASS** | parts in the zone: []; contact plate at rear face centre, z 115-180 (EST); coffee housing overhangs 54 mm behind the base at z >= 380 |
| Footprint | overall plan envelope | **PASS** | x -390..390, y -390..390 mm (Ranger Air 552 x 500); scanner pods at 2 corners, tray +-309, coffee module rear |
| Mass | HARD: superstructure + product payload (2 x 1.5 kg arms + 2.1 kg tray) <= 68 kg (15 % under the Ranger Air 80 kg); target <= 64 kg (20 %) | **PASS** | superstructure 54.2 kg + payload 5.1 kg = 59.3 kg = 74 % of 80 kg (margin 20.7 kg) |
| Mass | extension CoG within ±20 mm of the Ranger Air centre of rotation (plan centre), nominal: arms home, tray loaded | **PASS** | extension 56.3 kg, CoG (-17.7, 0.2, 788) mm |
| Mass | extension CoG, work posture (2 x 1.5 kg held at x 300 mm) | **PASS** | 59.3 kg, CoG (-1.7, 0.2, 800) mm (transient while handling) |
| Mass | info: robot mass | **PASS** | robot 104.2 kg (base 50 kg); sim robot (Tracer version) 130.5 kg |
| Stability | tipping nominal: >= 0.5 g target; >= 2.2 m/s2 required (Ranger Air decel not published: software accel limit) | **WARN** | fwd/back/left/right = 4.40/3.83/3.58/3.59 m/s2; CoG [-13. 0. 462.] mm; support ±194 x ±169 mm |
| Stability | tipping work: >= 0.5 g target; >= 2.2 m/s2 required (Ranger Air decel not published: software accel limit) | **WARN** | fwd/back/left/right = 3.92/3.88/3.39/3.40 m/s2; CoG [ -1. 0. 488.] mm; support ±194 x ±169 mm |
| Stability | tipping worst (product payload): >= 0.5 g target; >= 2.2 m/s2 required (Ranger Air decel not published: software accel limit) | **WARN** | fwd/back/left/right = 3.43/4.34/3.38/3.39 m/s2; CoG [ 23. 0. 490.] mm; support ±194 x ±169 mm |
| Bolt loads | G1 adapter->Ranger Air deck | **WARN** | 8x ISO 10642 M6x20 8.8; carried 51.5 kg; worst LC2 braking 0.5g rev: T=388 N, V_sum=253 N; F_V=6995 N (8.4 N.m); bolt 61% proof; slip OK (8306/316 N); shear 32/7718 N; strip 20.4 kN (manufacturer thread (datasheet max insertion), Le 12.0) vs 8.84 kN req; = 1.75 x proof — ASSUMED: Ranger Air top holes: positions SOURCED (200 x 80), thread M6 and depth >= 12 ASSUMED |
| Bolt loads | G2 column foot->adapter | **PASS** | 8x ISO 4762 M6x16 8.8; carried 32.9 kg; worst LC4 bump+braking: T=889 N, V_sum=162 N; F_V=6995 N (8.4 N.m); bolt 62% proof; slip OK (8140/202 N); shear 20/7718 N; strip 21.0 kN (EN AW-6082-T6, Le 8.0) vs 8.97 kN req; = 1.80 x proof |
| Bolt loads | G2b profile->column foot | **PASS** | 1x DIN 7984 M12x30 8.8; carried 31.7 kg; worst LC4 bump+braking: T=9339 N, V_sum=155 N; F_V=29336 N (70.4 N.m); bolt 64% proof; slip OK (3280/194 N); shear 155/32371 N; strip 93.5 kN (EN AW-6063-T66 (profile), Le 22.5) vs 39.01 kN req; = 1.91 x proof |
| Bolt loads | G3 profile->torso bracket | **PASS** | 1x DIN 7984 M12x30 8.8; carried 30.1 kg; worst LC4 bump+braking: T=6545 N, V_sum=148 N; F_V=29336 N (70.4 N.m); bolt 63% proof; slip OK (3615/185 N); shear 148/32371 N; strip 93.5 kN (EN AW-6063-T66 (profile), Le 22.5) vs 38.31 kN req; = 1.91 x proof |
| Bolt loads | G4 torso bracket->body_link0 | **WARN** | 8x ISO 4762 M6x30 8.8; carried 29.6 kg; worst LC2 lateral 0.5g R: T=388 N, V_sum=328 N; F_V=6995 N (8.4 N.m); bolt 61% proof; slip OK (8270/410 N); shear 59/7718 N; strip 15.6 kN (OpenArm body plate (Al, ASSUMED 5052), Le 8.0) vs 8.84 kN req; = 1.34 x proof — ASSUMED: docs.openarm.dev: 48x M6 taps on 30 mm grid; STL shows 5.5 mm holes -> if clearance, use M5x35 + nut |
| Bolt loads | G9 e-plates->adapter | **PASS** | 8x ISO 4762 M5x10 8.8; carried 3.2 kg; worst LC5 rebound (net -1g): T=9 N, V_sum=0 N; F_V=4942 N (4.9 N.m); bolt 60% proof; slip OK (5926/0 N); shear 0/5453 N; strip 15.3 kN (EN AW-6082-T6, Le 7.0) vs 6.18 kN req; = 1.86 x proof |
| Bolt loads | G10 scanner 0->pod | **WARN** | 4x ISO 4762 M5x10 8.8; carried 0.7 kg; worst LC4 bump+braking: T=1 N, V_sum=20 N; F_V=2471 N (2.5 N.m); bolt 30% proof; slip OK (1482/25 N); shear 6/5453 N; strip 8.5 kN (manufacturer thread (datasheet max insertion), Le 6.0) vs 3.09 kN req; = 1.03 x proof — ASSUMED: hole positions read from the SICK dimension chain (ASSUMED) |
| Bolt loads | G11 pod 0->adapter | **PASS** | 2x ISO 4762 M5x10 8.8; carried 1.0 kg; worst LC3 bump +2g: T=101 N, V_sum=0 N; F_V=4942 N (4.9 N.m); bolt 60% proof; slip OK (1458/0 N); shear 0/5453 N; strip 15.3 kN (EN AW-6082-T6, Le 7.0) vs 6.20 kN req; = 1.86 x proof |
| Bolt loads | G10 scanner 1->pod | **WARN** | 4x ISO 4762 M5x10 8.8; carried 0.7 kg; worst LC4 bump+braking: T=1 N, V_sum=20 N; F_V=2471 N (2.5 N.m); bolt 30% proof; slip OK (1482/25 N); shear 5/5453 N; strip 8.5 kN (manufacturer thread (datasheet max insertion), Le 6.0) vs 3.09 kN req; = 1.03 x proof — ASSUMED: hole positions read from the SICK dimension chain (ASSUMED) |
| Bolt loads | G11 pod 1->adapter | **PASS** | 2x ISO 4762 M5x10 8.8; carried 1.0 kg; worst LC4 bump+lateral: T=112 N, V_sum=17 N; F_V=4942 N (4.9 N.m); bolt 60% proof; slip OK (1456/21 N); shear 10/5453 N; strip 15.3 kN (EN AW-6082-T6, Le 7.0) vs 6.20 kN req; = 1.86 x proof |
| Bolt loads | G13 deck cover->standoffs | **PASS** | 4x ISO 7380 M5x16 8.8; carried 0.9 kg; worst LC2 lateral 0.5g L: T=0 N, V_sum=5 N; F_V=1235 N (1.2 N.m); bolt 15% proof; slip OK (741/6 N); shear 1/5453 N; strip 15.3 kN (EN AW-6082-T6, Le 7.0) vs 1.54 kN req; = 1.86 x proof |
| Bolt loads | G14 waist cover->bracket | **PASS** | 4x ISO 4762 M4x16 8.8; carried 0.5 kg; worst LC4 bump+lateral: T=5 N, V_sum=3 N; F_V=1528 N (1.2 N.m); bolt 30% proof; slip OK (915/3 N); shear 1/3372 N; strip 9.1 kN (EN AW-6082-T6, Le 5.2) vs 1.91 kN req; = 1.79 x proof |
| Bolt loads | G28 torso shell bracket front->post | **WARN** | 2x ISO 4762 M6x10 8.8; carried 0.3 kg; worst LC4 bump+braking: T=16 N, V_sum=9 N; F_V=1749 N (2.1 N.m); bolt 15% proof; slip OK (523/11 N); shear 4/7718 N; T-nut allow 2500 N (ASSUMED) vs F_V+T 1765 N — ASSUMED: post slot ASSUMED (Misumi 60 series) |
| Bolt loads | G29 torso shell front half->bracket | **PASS** | 1x ISO 4762 M4x12 8.8; carried 0.3 kg; worst LC4 bump+lateral: T=8 N, V_sum=7 N; F_V=356 N (0.3 N.m); bolt 7% proof; slip OK (52/9 N); shear 7/3372 N; insert pull-out 1500 N (ESTIMATE) vs 1.5 x 365 N |
| Bolt loads | G28 torso shell bracket rear->post | **WARN** | 2x ISO 4762 M6x10 8.8; carried 0.3 kg; worst LC4 bump+braking: T=18 N, V_sum=9 N; F_V=1749 N (2.1 N.m); bolt 15% proof; slip OK (522/12 N); shear 5/7718 N; T-nut allow 2500 N (ASSUMED) vs F_V+T 1767 N — ASSUMED: post slot ASSUMED (Misumi 60 series) |
| Bolt loads | G29 torso shell rear half->bracket | **PASS** | 1x ISO 4762 M4x12 8.8; carried 0.3 kg; worst LC4 bump+lateral: T=10 N, V_sum=8 N; F_V=356 N (0.3 N.m); bolt 7% proof; slip OK (52/10 N); shear 8/3372 N; insert pull-out 1500 N (ESTIMATE) vs 1.5 x 366 N |
| Bolt loads | G15 neck plate->body_link0 | **WARN** | 4x ISO 4762 M4x18 8.8; carried 0.6 kg; worst LC2 braking 0.5g fwd: T=3 N, V_sum=3 N; F_V=3055 N (2.4 N.m); bolt 60% proof; slip OK (1833/4 N); shear 1/3372 N; strip 8.1 kN (OpenArm body plate (Al, ASSUMED 5052), Le 6.2) vs 3.82 kN req; = 1.58 x proof — ASSUMED: no published holes on the OpenArm J1 housing top: ASSUMED 4x M4, verify with Enactic CAD |
| Bolt loads | G16 head shell->neck plate | **PASS** | 4x ISO 4762 M4x12 8.8; carried 0.1 kg; worst LC5 rebound (net -1g): T=1 N, V_sum=0 N; F_V=356 N (0.3 N.m); bolt 7% proof; slip OK (214/0 N); shear 0/3372 N; insert pull-out 1500 N (ESTIMATE) vs 1.5 x 357 N |
| Bolt loads | G18 Gemini->bracket | **WARN** | 2x ISO 4762 M4x6 8.8; carried 0.1 kg; worst LC4 bump+lateral: T=3 N, V_sum=3 N; F_V=255 N (0.2 N.m); bolt 5% proof; slip OK (76/3 N); shear 1/3372 N; strip 4.0 kN (manufacturer thread (datasheet max insertion), Le 3.5) vs 0.32 kN req; = 0.78 x proof — ASSUMED: Gemini back M4 max insertion 4 mm, 0.4 N.m (SOURCED): bolt L = t + 3.5 |
| Bolt loads | G19 Gemini bracket->post | **WARN** | 2x ISO 4762 M6x10 8.8; carried 0.2 kg; worst LC4 bump+lateral: T=15 N, V_sum=8 N; F_V=1749 N (2.1 N.m); bolt 15% proof; slip OK (522/10 N); shear 4/7718 N; T-nut allow 2500 N (ASSUMED) vs F_V+T 1764 N — ASSUMED: post slot ASSUMED (Misumi 60 series) |
| Bolt loads | G20 tray carrier->post | **WARN** | 4x ISO 4762 M6x10 8.8; carried 4.3 kg; worst LC4 bump+lateral: T=437 N, V_sum=156 N; F_V=1749 N (2.1 N.m); bolt 16% proof; slip OK (966/195 N); shear 47/7718 N; T-nut allow 2500 N (ASSUMED) vs F_V+T 2186 N — ASSUMED: post slot ASSUMED (Misumi 60 series) |
| Bolt loads | G21 coffee uprights->adapter | **PASS** | 4x ISO 4762 M5x10 8.8; carried 6.1 kg; worst LC2 braking 0.5g rev: T=152 N, V_sum=30 N; F_V=4942 N (4.9 N.m); bolt 60% proof; slip OK (2930/38 N); shear 9/5453 N; strip 17.5 kN (EN AW-6082-T6, Le 8.0) vs 6.21 kN req; = 2.13 x proof |
| Bolt loads | G22 shelf->uprights | **PASS** | 4x ISO 4762 M4x8 8.8; carried 5.6 kg; worst LC2 braking 0.5g rev: T=18 N, V_sum=27 N; F_V=3055 N (2.4 N.m); bolt 60% proof; slip OK (1830/34 N); shear 9/3372 N; strip 10.5 kN (EN AW-6082-T6, Le 6.0) vs 3.82 kN req; = 2.07 x proof |
| Bolt loads | G23 MGN12 rail->shelf | **PASS** | 3x ISO 4762 M3x16 8.8; carried 0.5 kg; worst LC2 braking 0.5g rev: T=2 N, V_sum=2 N; F_V=1750 N (1.1 N.m); bolt 60% proof; slip OK (787/3 N); shear 1/1932 N; strip 7.9 kN (EN AW-6082-T6, Le 6.0) vs 2.19 kN req; = 2.70 x proof |
| Bolt loads | G24 cup carrier->carriage | **PASS** | 4x ISO 4762 M3x8 8.8; carried 0.2 kg; worst LC4 bump+braking: T=12 N, V_sum=5 N; F_V=583 N (0.4 N.m); bolt 20% proof; slip OK (348/6 N); shear 1/1932 N; strip 7.4 kN (S235 / 1.4301, Le 3.5) vs 0.73 kN req; = 2.54 x proof |
| Bolt loads | G25 actuator bracket->shelf | **PASS** | 2x ISO 4762 M4x10 8.8; carried 0.1 kg; worst LC5 rebound (net -1g): T=197 N, V_sum=90 N; F_V=3055 N (2.4 N.m); bolt 61% proof; slip OK (869/112 N); shear 62/3372 N; strip 10.5 kN (EN AW-6082-T6, Le 6.0) vs 3.87 kN req; = 2.07 x proof |
| Bolt loads | G26 cup holder->shelf | **PASS** | 3x ISO 4762 M4x16 8.8; carried 0.3 kg; worst LC2 braking 0.5g rev: T=3 N, V_sum=1 N; F_V=356 N (0.3 N.m); bolt 7% proof; slip OK (160/2 N); shear 0/3372 N; insert pull-out 1500 N (ESTIMATE) vs 1.5 x 360 N |
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

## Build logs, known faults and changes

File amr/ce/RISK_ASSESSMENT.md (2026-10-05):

# Risk assessment - Giorgio (EN ISO 12100:2010) - v0.5 draft, design rev B3, 2026-10-05

Hazard register: `risk_assessment.csv` (44 rows). This file gives limits, method, safety functions and the summary.
Status: DRAFT by design review, no tests yet. All numeric limits marked ASSUMED are proposals to be fixed in the SRS.
Rev B: no waist joint. The rev A waist hazards (rotating superstructure, waist-plate shear gap, twisterband/ring-bearing
entanglement) no longer exist and were deleted; hazard and SF IDs were renumbered.

## 1. Limits of the machinery (ISO 12100 cl. 5.3)
- **Intended use**: autonomous mobile bimanual service robot: transport of light items (2 x 3 kg in hands, 2.1 kg tray),
  barista service (24 V capsule coffee module), pick/place on tables/counters; indoor, flat floors.
- **Users**: trained operator/supervisor (professional), maintainer (trained by manufacturer); exposed persons =
  public incl. children, elderly, persons with reduced mobility or sight (barista variant).
- **Space**: indoor, slope <= 3 % travel (ASSUMED, ISO 3691-4 site requirement), dry floor, 0-40 C, no ATEX, no
  outdoor. Footprint 780 x 560 mm; swept radius when rotating in place ~440 mm with arms parked (base ~432 mm ESTIMATE,
  superstructure 440 mm from CAD `../out/integration.json`).
- **Mass**: ~146 kg empty (base 102.2 kg + superstructure 43.7 kg, rev B CAD), ~155 kg loaded.
- **Time**: 8-10 h/day, battery 3.07 kWh; life 5 years (ASSUMED); maintenance intervals in manual.
- **Variants**: C48 = certified DC cobot arms (CE-fast); OA = OpenArm 2.0 (R&D, external safety only).
- **Foreseeable misuse**: pushing/leaning/climbing, children touching gaps, handing objects directly to hands,
  driving with items in grippers, operation outdoors/wet floors, tampering with fields, use without supervisor.

## 2. Method
- Life-cycle phases: transport, installation/commissioning, operation (auto travel, rotate in place, manipulation,
  barista, docking), manual/service mode, cleaning, maintenance, decommissioning.
- Risk estimate: S (1 first aid, 2 reversible lost-time, 3 irreversible, 4 fatal) x O (1 improbable, 2 remote,
  3 occasional, 4 likely) = R. R <= 3 low (accept); 4-6 medium (accept only if ALARP + information); >= 8 not acceptable.
  S0/O0 = before measures, S1/O1 = residual.
- PLr per EN ISO 13849-1:2023 Annex A graph (S1/S2, F1/F2, P1/P2), cross-checked with the PL table of
  EN ISO 3691-4:2023 cl. 4 and EN ISO 10218-2:2025; the higher value wins.
- Three-step method (ISO 12100 cl. 6): inherent design -> safeguards/complementary measures (SF) -> information.

## 3. Safety functions (rev B2, same IDs as B1, used in the CSV and in all `ce/` files)
**SF1-SF16 are the electrical numbering** of `../electrical/SAFETY_FUNCTIONS.md` rev B2 (same IDs, same order; devices,
PFHd and stop categories live there). SF17 is CE-only: there is no matching function in the electrical package (closest
item: the Jetson heartbeat, which is non-safety), so it keeps its ID and must be added to the electrical stream as a
functional (non-safety-rated) requirement. Safety controller rev B2: **Pilz PNOZmulti 2** (PNOZ m B0 + 2 x EF 4DI4DOR
relay modules + ES ETH; C48 adds one EF 8DI4DO). The SWD STO/INSafe inputs and the scanner control inputs are driven by
positive-guided relay contacts with bleed resistors (`../VERIFICATION.md` E6/S4).

| ID | Safety function | Implementation (summary) | PLr | electrical rev B1 | electrical rev A1 |
|---|---|---|---|---|---|
| SF1 | Emergency stop (3 x Siemens 3SU1 with 2 x 3SU1400-1AA10-1CA0 NC: ES1+ES2 base in series, ES3 torso) | PNOZ m B0 -> SR1 relays -> SWD SS1-t (SLS request at once, STO+SBC at 1.2 s after a complete 1.5 m/s2 ramp, ramp ends by 0.827 s from 1.1 m/s); arms: K1/K2 with mirror-contact EDM (OA) or cobot E-stop input (C48); coffee K4 off | d | SF1 | SF1 |
| SF2 | Protective stop on person detection | 2x nanoScan3 Pro I/O OSSD1 -> PNOZ -> SWD STO+SBC, arm stop | d | SF2 | SF2 |
| SF3 | Speed-dependent protective field switching | 3 field sets (FS1 FAST / FS2 SLOW + arm field / FS3 DOCK) selected 1-of-3 through SR2 relay contacts (single contact fault -> invalid code -> OSSD off); SLS request first, field change after 1.1 s (t_SLS 1.0 s) | d | SF3 | SF3 |
| SF4 | Safe limited speed per mode | SWD SMS 1.1 m/s permanent (rev B4: castor rating speed); SLS[2] 0.7 m/s in MEDIUM (SR3); SLS[1] 0.3 m/s in SLOW/DOCK/MANUAL/arms not parked; STO in SERVICE | d | SF4 | SF4 |
| SF5 | Safe limited reverse speed | **reverse <= 0.3 m/s as a permanent SLSa in each SWD** (forward <= 1.1 m/s); no controller channel; replaces the rev A SDI | d | SF5 | SF5 (SDI) |
| SF6 | Safe standstill of the base while the arms work | K1/K2 close only with traction STO + SBC (spring-applied brakes) | d | SF6 | SF6 |
| SF7 | Arms move only with the arm protective field clear (OA) / protective stop of certified arms (C48) | scanner OSSD2 (arm field in FS2) -> K1/K2 SS1-t (OA) or arm safeguard-stop input via SX2 (C48); SSM distance per EN ISO 13855 | d | SF7 | SF7 |
| SF8 | Carry mode: FAST travel only with arms parked (and de-energised for OA) | 2 Pilz PSEN cs3.1 arm-rest sensors, each on its own PNOZ input pair + K1/K2 EDM (OA) / arm "stopped" output (C48) | d | SF8 | SF8 |
| SF9 | Docking field (reduced rear field shaped to the dock, no muting) | FS3 only with SLS 0.3 m/s active, arms off | c | SF9 | SF11 |
| SF10 | Charging contacts dead unless docked | ideal diode (no back-feed) + station contactor closes only with Hall + signature + Wi-Fi/Ethernet handshake (RoboPad has no wireless CAN); dock OV relay 59 V (RoboPad <= 60 V under fault); robot-side KS relay on a PNOZ auxiliary output (functional) | c | SF10 | SF12 |
| SF11 | No traction while charging is permitted | PNOZ holds SWD STO while KS is energised | c | SF11 | SF13 |
| SF12 | Battery protection | Discover BMS (IEC 62619 CB, main relay) primary; independent layers without PL credit: F0 3NA3830 100 A gG; K0 opened by the G01 LYNK II relay R1 NO "energised = OK" (fail-safe) and by K0V at 48 V; charger CV DIP preset 56.8 V | d (no BMS PL published: no PL credit, VERIFICATION D13) | SF12 | SF14 |
| SF13 | Manual reset, no automatic restart after E-stop | blue reset button SB1 with view of the robot, edge-evaluated in the PNOZ | d | SF13 | SF15 |
| SF14 | Mode selection (AUTO/MANUAL/SERVICE) and manual mode | key selector SK1; MANUAL = SLS 0.3 m/s + 3-position enabling pendant SE1; SERVICE = STO + arm/coffee power off | d | SF14 | SF16 |
| SF15 | Coffee module stop | KI4 interposing relay on a PNOZ auxiliary output -> K4 (Cat B) with aux read-back, off on E-stop and in SERVICE; cover/tilt interlock see H13 | **b (to confirm, H13; was c)** | SF15 | SF17 |
| SF16 | Collaborative hand-over / PFL (C48 only) | cobot PL d functions (PFL, SLS, SLP, SS1/SS2) + SSM (SF7); impossible with OpenArm | d | SF16 | SF18 |
| SF17 | Supervisory/communication watchdog (MR 3.2.4) | heartbeat loss -> protective stop + safe park (non-safety software on the Jetson) | b | **not yet in the electrical package** | - (CE only) |

Removed in rev B: electrical rev A1 SF9 (waist safe limited speed) and SF10 (waist safe limited position); rev A CE SF5
(waist safe motion) and SF6 (superstructure/waist motion permit; its arm part is now SF7).

**Coffee stop PLr (SF15), argument to confirm in this assessment.** The relevant rows are H13 (thermal), H14 (shuttle
pinch) and H43 (fire). H13: hot water stays inside an EN 60335-2-15 appliance in the SH06 enclosure, the outlet is only
above the cup holder, the shuttle force is low -> risk-graph **S1** (slight, normally reversible burn), **F2** (barista
operation all shift), **P1** (heating and ejection are slow and visible, the person can withdraw) -> **PLr b**. H14:
S1 F1 P1 -> a. H43 is covered by the heater thermal fuse and FCF, not by a stop function. So SF15 PLr = b and K4 on a
standard output (Cat B, PL b) is sufficient. **If the assessment rates H13 as S2** (e.g. scald of a child's face or of a
seated person at the outlet height, or hot-water ejection when the cover is opened during brewing) -> PLr c -> fallback
from `../electrical/` rev B2: KI4 on a free B0 safe SC output (O1, €0) plus the U7 remote OFF as a diverse channel.
The rev A cover-open and tilt inputs are not in the rev B2 I/O list: either rely on the appliance's own cover interlock
(EN 60335-2-15 evidence, G5) or wire a cover switch to a spare PNOZ input (B0 + 2 EF 4DI4DOR has 28 inputs, 26 used; SR2 I2 reserved for it).

## 4. Summary of residual risks (from CSV)
| R1 | Rows | Comment |
|---|---|---|
| 6 (medium) | H08, H10 | OpenArm variant only: arm collision without PFL and **arm drop on power loss** -> not acceptable for public until GAPS G1 (brakes/gravity compensation, MR Annex III 1.2.6(d)) is closed; R&D/lab use only |
| 3 (low) + residual note | H03 | rev B2 SS1-t: a fault of the non-safe ramp is stopped by the SWD SLS-STO at 1.0 s (PL d) and the PNOZ STO at 1.2 s; the distance exceeds the field (CALC §7 info). Single fault of a non-safety part; evidence TP-01b; G16 |
| 4 (medium) | H04, H15, H22, H25, H27 | overhangs above scan plane, tip-over (S4), edges/stairs (site barriers required), battery fire (S4, O1), dock mains (S4, O1): accepted with information for use + site requirements |
| <= 3 | all others | acceptable |

Residual risks to state in the manual (Annex III 1.7.2, 1.7.4.2(l)): H04, H05, H12, H15, H16, H21, H22, H25, H37.

## 5. Next steps
1. SRS per SF (reaction time, stop category, PFHd budget) and SISTEMA calculation with the Pilz PNOZmulti 2 library
   (controller frozen 2026-10-05); confirm the SF15 PLr b argument (§3); add SF17 to the electrical package.
2. Fix ASSUMED numbers (speeds, slope) from TEST_PLAN results; re-score.
3. Re-run this assessment for each variant and after every design change (version + date in this header).

**Rev B3 additions:** H02/H03 (fields): the scan plane must stay ≤ 200 mm at every field edge (SICK OI 8024596 p.40); the body pitches on the sprung castors, so the motion profile has per-band accel/decel limits (`../CALC.md` §7b) and TP-05/05b verify the plane (static 184.5 ± 5 mm, dynamic ≤ 200 mm). During an SS1-t stop at 1.5 m/s² the rear plane rises to ≈ 204 mm for ≤ 1.1 s while the robot moves away from the rear field: no approach hazard, recorded with H03. H05/H15: D80 castors climb sharp steps ≤ 10 mm; 10-20 mm thresholds only bevelled ≤ 1:2 at ≤ 0.3 m/s (site requirement + manual).

**Rev B4 additions (CERTAINTY.md F1-F5, G-04):** H02/H03: protective fields now include the SICK ground-clearance supplement Z_F =
150 mm in length and width (OI 8024596 p.37-39) and the arm-work field includes T_Z with 50 mm resolution (p.30-31); top speed
1.1 m/s (published castor rating speed), bands 0.3 / 0.7 / 1.1 m/s with SLS[2] on a third relay module (SR3). H20: the DSR 50/5 clamps
sink ≤ 5 A each at 27 V (270 W for two vs 200 W peak regen); if one trips on over-temperature the clamp is released and T24 rises to the
DDR OVP / SWD OV limits, which switch traction off; the STO path is independent (TP-14 with one clamp disconnected). New H45: the SWD
drives (rated 0…+40 °C) run in their own tunnels on room air; the robot is rated for a room ambient of 0…+35 °C (TP-11 heat-run).

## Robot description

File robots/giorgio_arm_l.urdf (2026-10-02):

<robot name="giorgio_arm_l">
<link name="base_link" />
<link name="link1"><inertial><origin xyz="0 0 -0.05" /><mass value="0.8" /><inertia ixx="0.004" iyy="0.004" izz="0.002" ixy="0" ixz="0" iyz="0" /></inertial>
<visual><origin xyz="0 0 0" /><geometry><sphere radius="0.065" /></geometry></visual>
</link>
<joint name="l_shoulder_pitch" type="revolute"><parent link="base_link" /><child link="link1" /><origin xyz="0 0 0" /><axis xyz="0 1 0" /><limit lower="-3.0" upper="1.0" effort="120.0" velocity="3.0" /></joint>
<link name="link2"><inertial><origin xyz="0 0 -0.05" /><mass value="0.9" /><inertia ixx="0.004" iyy="0.004" izz="0.002" ixy="0" ixz="0" iyz="0" /></inertial>
<visual><origin xyz="0 0.01 -0.02" /><geometry><box size="0.11 0.13 0.09" /></geometry></visual>
</link>
<joint name="l_shoulder_roll" type="revolute"><parent link="link1" /><child link="link2" /><origin xyz="0 0 0" /><axis xyz="1 0 0" /><limit lower="-0.35" upper="1.7" effort="120.0" velocity="3.0" /></joint>
<link name="link3"><inertial><origin xyz="0 0 -0.05" /><mass value="1.6" /><inertia ixx="0.004" iyy="0.004" izz="0.002" ixy="0" ixz="0" iyz="0" /></inertial>
<visual><origin xyz="0 0 -0.15" /><geometry><cylinder radius="0.042" length="0.24" /></geometry></visual>
<visual><origin xyz="0.01 0 -0.13999999999999999" /><geometry><box size="0.075 0.07 0.17" /></geometry></visual>
</link>
<joint name="l_shoulder_yaw" type="revolute"><parent link="link2" /><child link="link3" /><origin xyz="0 0 0" /><axis xyz="0 0 1" /><limit lower="-2.2" upper="2.2" effort="60.0" velocity="3.0" /></joint>
<link name="link4"><inertial><origin xyz="0 0 -0.05" /><mass value="0.4" /><inertia ixx="0.004" iyy="0.004" izz="0.002" ixy="0" ixz="0" iyz="0" /></inertial>
<visual><origin xyz="0 0 0" /><geometry><sphere radius="0.05" /></geometry></visual>
</link>
<joint name="l_elbow" type="revolute"><parent link="link3" /><child link="link4" /><origin xyz="0 0 -0.3" /><axis xyz="0 1 0" /><limit lower="-2.6" upper="0.0" effort="60.0" velocity="3.0" /></joint>
<link name="link5"><inertial><origin xyz="0 0 -0.05" /><mass value="1.1" /><inertia ixx="0.004" iyy="0.004" izz="0.002" ixy="0" ixz="0" iyz="0" /></inertial>
<visual><origin xyz="0 0 -0.13" /><geometry><cylinder radius="0.036" length="0.20" /></geometry></visual>
<visual><origin xyz="0.012 0 -0.11" /><geometry><box size="0.06 0.065 0.13" /></geometry></visual>
</link>
<joint name="l_wrist_yaw" type="revolute"><parent link="link4" /><child link="link5" /><origin xyz="0 0 0" /><axis xyz="0 0 1" /><limit lower="-2.6" upper="2.6" effort="20.0" velocity="3.0" /></joint>
<link name="link6"><inertial><origin xyz="0 0 -0.05" /><mass value="0.3" /><inertia ixx="0.004" iyy="0.004" izz="0.002" ixy="0" ixz="0" iyz="0" /></inertial>
<visual><origin xyz="0 0 0" /><geometry><sphere radius="0.038" /></geometry></visual>
</link>
<joint name="l_wrist_pitch" type="revolute"><parent link="link5" /><child link="link6" /><origin xyz="0 0 -0.26" /><axis xyz="0 1 0" /><limit lower="-1.7" upper="1.7" effort="20.0" velocity="3.0" /></joint>
<link name="link7"><inertial><origin xyz="0 0 -0.05" /><mass value="0.25" /><inertia ixx="0.004" iyy="0.004" izz="0.002" ixy="0" ixz="0" iyz="0" /></inertial>
<visual><origin xyz="0 0 -0.015" /><geometry><cylinder radius="0.034" length="0.03" /></geometry></visual>
</link>
<joint name="l_wrist_roll" type="revolute"><parent link="link6" /><child link="link7" /><origin xyz="0 0 -0.02" /><axis xyz="0 0 1" /><limit lower="-2.9" upper="2.9" effort="15.0" velocity="3.0" /></joint>
<link name="tool0" />
<joint name="l_tool" type="fixed"><parent link="link7" /><child link="tool0" /><origin xyz="0 0 -0.030000000000000002" rpy="3.14159265 0 0" /></joint>
<link name="gripper_body"><inertial><origin xyz="0 0 0.025" /><mass value="0.9" /><inertia ixx="1e-4" iyy="1e-4" izz="1e-4" ixy="0" ixz="0" iyz="0" /></inertial><visual><origin xyz="0 0 0.025" /><geometry><box size="0.09 0.130 0.05" /></geometry><material name="m_gripper_body"><color rgba="0.15 0.15 0.17 1" /></material></visual></link><joint name="gripper_mount" type="fixed"><parent link="tool0" /><child link="gripper_body" /><origin xyz="0 0 0" /></joint><link name="finger_left"><inertial><origin xyz="0 0.01 0" /><mass value="0.1" /><inertia ixx="1e-4" iyy="1e-4" izz="1e-4" ixy="0" ixz="0" iyz="0" /></inertial><visual><origin xyz="0 0.012 0" /><geometry><box size="0.05 0.016 0.05" /></geometry><material name="m_finger_left"><color rgba="0.75 0.76 0.8 1" /></material></visual><collision><origin xyz="-0.016 0.01 0" /><geometry><box size="0.014 0.02 0.05" /></geometry></collision><collision><origin xyz="0.016 0.01 0" /><geometry><box size="0.014 0.02 0.05" /></geometry></collision></link><joint name="finger_left_joint" type="prismatic"><parent link="gripper_body" /><child link="finger_left" /><origin xyz="0 0 0.07500000000000001" /><axis xyz="0 1 0" /><limit lower="0" upper="0.035" effort="60.0" velocity="0.2" /></joint><link name="finger_right"><inertial><origin xyz="0 -0.01 0" /><mass value="0.1" /><inertia ixx="1e-4" iyy="1e-4" izz="1e-4" ixy="0" ixz="0" iyz="0" /></inertial><visual><origin xyz="0 -0.012 0" /><geometry><box size="0.05 0.016 0.05" /></geometry><material name="m_finger_right"><color rgba="0.75 0.76 0.8 1" /></material></visual><collision><origin xyz="-0.016 -0.01 0" /><geometry><box size="0.014 0.02 0.05" /></geometry></collision><collision><origin xyz="0.016 -0.01 0" /><geometry><box size="0.014 0.02 0.05" /></geometry></collision></link><joint name="finger_right_joint" type="prismatic"><parent link="gripper_body" /><child link="finger_right" /><origin xyz="0 0 0.07500000000000001" /><axis xyz="0 -1 0" /><limit lower="0" upper="0.035" effort="60.0" velocity="0.2" /></joint></robot>

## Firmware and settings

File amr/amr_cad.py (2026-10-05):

"""Giorgio AMR (own base), rev B4 - parametric CadQuery model: chassis, 2 safety wheel drives, 4 sprung castors,
2 batteries, centre electronics bay, DIN bays, safety scanners, dock contacts, covers, cable harness routes and the
charging dock. Rev B2 (CAD_REV_B2.md): batteries on their side with the top cover outward, Mean Well / Discover
installation rules as invisible keep-out solids (category 'keepout'). Rev B3 (CAD_REV_B3.md): sprung D80 castors on
MGN15 guides in the spine/battery gaps with swivel keep-outs, DIN layout = electrical/din_layout.md rev B3, LYNK II at its real size. Rev B4 (CAD_REV_B4.md): SWD 125 at its documented 196 mm / 7 kg in drive tunnels E43 (F3/F4), centre bay rearranged, deck doubler A09, PCAN and NPB-750 at their real sizes, SR3 for the 0.7 m/s band. Rev B has no waist joint: the 15 mm top deck is the superstructure flange (top at z = 353 mm).

    cad/.env/bin/python amr/amr_cad.py            # build, export STEP/STL/DXF, parts.json, mass properties

Frame as cad/: mm, origin on the floor at the base centre, x forward, y left, z up, waist yaw = 0.
Purchased parts are datasheet envelopes (tag ESTIMATE where the manufacturer CAD is not public): replace them with
the vendor STEP before release (list in DESIGN.md).
"""
from __future__ import annotations

import json
import math
import sys
from pathlib import Path

import cadquery as cq
import numpy as np
import trimesh

HERE = Path(__file__).resolve().parent
sys.path.insert(0, str(HERE.parent / "cad"))
import geom as G  # noqa: E402
from geom import box, cyl  # noqa: E402
from amr_params import *  # noqa: E402,F401,F403

OUT = HERE / "out"
RHO = {"S355MC": 7850, "EN AW-6082-T6": 2700, "EN AW-5754-H22": 2670, "POM-C": 1410, "PA12 (MJF)": 1010,
       "EPDM": 1200, "steel 42CrMo4": 7850, "purchased": 0, "harness": 0}
COL = {"S355MC": (0.30, 0.31, 0.33), "EN AW-6082-T6": (0.74, 0.75, 0.77), "EN AW-5754-H22": (0.80, 0.81, 0.83),
       "POM-C": (0.95, 0.95, 0.93), "PA12 (MJF)": (0.93, 0.93, 0.91), "EPDM": (0.07, 0.07, 0.08), "steel 42CrMo4": (0.5, 0.5, 0.52)}
PARTS: dict = {}


def add(name, shape, material, process, group="base", category="custom", color=None, explode=(0, 0, 0), mass=None,
        src="", flat=None, qty=1, notes=""):
    """flat = (z_cut, thickness) for laser/waterjet parts -> a DXF profile is exported"""
    m = mass if mass is not None else shape.Volume() * 1e-9 * RHO[material]
    PARTS[name] = dict(shape=shape, material=material, process=process, group=group, category=category,
                       color=color or COL.get(material, (0.2, 0.2, 0.22)), explode=explode, mass=m, src=src, flat=flat,
                       qty=qty, notes=notes)
    return shape


def poly(pts, t, z0):
    return cq.Workplane("XY", origin=(0, 0, z0)).polyline(pts).close().extrude(t).val()


def outline(inset=0.0, chamf=CHAMF):
    x0, x1, y0, y1 = X0 + inset, X1 - inset, Y0 + inset, Y1 - inset
    c = chamf - inset * (math.sqrt(2) - 1)
    return [(x1, y0 + c), (x1, y1 - c), (x1 - c, y1), (x0 + c, y1), (x0, y1 - c), (x0, y0 + c), (x0 + c, y0), (x1 - c, y0)]


def place(shape, R=np.eye(3), t=(0, 0, 0)):
    return G.transform_shape(shape, R, t)


def tube(points, r):
    """harness as a swept circle along a polyline (rounded corners)"""
    pts = [cq.Vector(*p) for p in points]
    path = cq.Wire.makePolygon(pts, close=False)
    try:
        path = cq.Wire.assembleEdges(path.Edges()).fillet(min(25.0, r * 4)) if len(pts) > 2 else path
    except Exception:
        pass
    d = (pts[1] - pts[0]).normalized()
    circ = cq.Wire.makeCircle(r, pts[0], d)
    return cq.Solid.sweep(circ, [], path, transitionMode="round")


# ====================================================================== keep-outs (rev B2)
def keepout(name, shape, owner, rule):
    """invisible check solid: free space required by a manufacturer installation rule. Not exported as a part, not rendered,
    0 kg; checked against every solid except its owner (and other keep-outs: overlapping free spaces are allowed)."""
    PARTS[f"KO_{name}"] = dict(shape=shape, material="purchased", process="keep-out (check solid)", group="keepout",
                               category="keepout", color=(1.0, 0.0, 1.0), explode=(0, 0, 0), mass=0.0, src=rule, flat=None,
                               qty=1, notes=f"owner={owner}", owner=owner if isinstance(owner, tuple) else (owner,))
    return shape


MW_RULE = "Mean Well DDR/DRDN installation manual: vertical, input terminals down, 40 mm above, 20 mm below, 5 mm left/right"


def din(name, x0, dims, zc, face, side, conv=False, color=None, mass=0.25, explode=(0, 0, 0), process=None, src="", notes=""):
    """DIN module on a rail. face = y of the rail front face, side = +1/-1 direction of the module depth.
    conv=True adds the Mean Well keep-out (KO_<name>) around it."""
    w, h, d = dims
    y0, y1 = sorted((face, face + side * d))
    s = box(x0, x0 + w, y0, y1, zc - h / 2, zc + h / 2)
    col = color or ((0.78, 0.78, 0.8) if conv else (0.85, 0.12, 0.1) if "contactor" in name else (0.25, 0.25, 0.28))
    add(name, s, "purchased", process or "purchased DIN module (amr/electrical/din_layout.md, netlist_amr.yaml)", category="purchased",
        color=col, explode=explode, mass=mass, src=src, notes=notes)
    if conv:
        k, a, b = CONV_KO["side"], CONV_KO["above"], CONV_KO["below"]
        keepout(name, box(x0 - k, x0 + w + k, y0, y1, zc - h / 2 - b, zc + h / 2 + a).cut(s), name, MW_RULE)
    return s


def rail(name, xa, xb, zc, face_from, face_to, explode=(0, 0, 0), notes="DIN rail TS35x7.5 EN 60715, M5 to the spine"):
    add(name, box(xa, xb, face_from, face_to, zc - 17.5, zc + 17.5), "purchased", notes, category="purchased",
        color=(0.7, 0.7, 0.72), explode=explode, mass=0.25 * (xb - xa) / 516)


# ====================================================================== structure
CORNERS = [(1, 1, "FL"), (1, -1, "FR"), (-1, 1, "RL"), (-1, -1, "RR")]
SCAN_TAGS = {"FR", "RL"}                                 # scanner corners (SCAN_CORNERS); FL / RR carry corner DIN rails instead


def lbox(sx, sy, u0, u1, v0, v1, z0, z1):
    """box in castor-local coordinates (CASTOR_SUSPENSION.md s.6): u = sx*(x - sx*xc), v = sy*(y - sy*yc), outboard positive"""
    xc, yc = CASTER_XY
    return box(sx * (xc + u0), sx * (xc + u1), sy * (yc + v0), sy * (yc + v1), z0, z1)


def lpt(sx, sy, u, v):
    return sx * (CASTER_XY[0] + u), sy * (CASTER_XY[1] + v)


def chassis():
    pan = poly(outline(6.0), PAN_T, PAN_Z0)
    # wheel wells (wheel + 12 mm clearance) and caster holes
    for sy in (-1, 1):
        pan = pan.cut(box(-WHEEL_D / 2 - 14, WHEEL_D / 2 + 14, sy * (WHEEL_Y - WHEEL_W / 2 - 10), sy * (WHEEL_Y + WHEEL_W / 2 + 12),
                          PAN_Z0 - 1, PAN_Z1 + 1))
    for sx, sy, _ in CORNERS:                            # rev B3: corner cut r 86 about the castor axis (opens the pan chamfer edge)
        pan = pan.cut(cyl(PAN_CUT_R, PAN_T + 2, (sx * CASTER_XY[0], sy * CASTER_XY[1], PAN_Z0 - 1)))
    for sy in (-1, 1):                                    # rev B4: slot for the coaxial SWD body (D118) from the tunnel inlet to the wheel well
        pan = pan.cut(box(-62, 62, min(sy * 22, sy * 200), max(sy * 22, sy * 200), PAN_Z0 - 1, PAN_Z1 + 1))
    add("A01_floor_pan", pan, "S355MC", "laser cut 5 mm S355MC, deburr, zinc-flake or powder coat; PEM studs M6; corner cuts r 86 about the castor axes; rev B4 SWD slots |x| 62, |y| 22..200 (tunnel inlet + body)",
        explode=(0, 0, -160), flat=(PAN_Z0, PAN_T), notes="low and heavy on purpose: ballast for tipping; rev B3: castor loads go to the spines, not the pan")

    deck = poly(outline(4.0), DECK_T, DECK_Z0)
    cx_, cy_, lx_, ly_ = CABLE_PASS
    deck = deck.cut(G.rounded_rect(cx_, cy_, lx_, ly_, DECK_T + 2, DECK_Z0 - 1, 12))      # grommet: base -> superstructure cables
    jx = (JETSON_BOX[0] + JETSON_BOX[1]) / 2
    deck = deck.cut(G.rounded_rect(jx, -23, 40, 30, DECK_T + 2, DECK_Z0 - 1, 8))           # rev B2: Jetson cables, under cover K06
    add("A02_top_deck", deck, "EN AW-6082-T6", "waterjet 15 mm 6082-T6 + CNC: column-foot M6 pattern (thread engagement >= 9 mm) and coffee-upright holes (as old P01), spine slots, K06/E51 M4 pattern + cable hole with edge protection; M4 for the DSR plates and the LYNK bracket underneath; powder coat RAL 9016 textured",
        explode=(0, 0, 260), flat=(DECK_Z0, DECK_T), notes="IS the superstructure flange (old P01 + Ranger deck in one part); bolted to both spines, 3 end posts and brackets A06/A07/A08")

    nx0, nx1, nz0, nz1 = SPINE_NOTCH
    for sy in (-1, 1):
        y0 = sy * SPINE_Y - (SPINE_T if sy > 0 else 0)
        sp = box(-SPINE_X, SPINE_X, y0, y0 + SPINE_T, PAN_Z1, DECK_Z0)
        sp = sp.cut(box(-TUNNEL["x"] - 1, TUNNEL["x"] + 1, y0 - 1, y0 + SPINE_T + 1, PAN_Z1 - 1, TUNNEL["z_top"] + 1))   # rev B4: drive notch (SWD body + tunnel E43 pass through)
        for x in (-230, -140, 230):                                                      # harness windows (also the passive air return); rev B3 x +-200 -> +-230 (castor rails at |x| 177.5..192.5)
            sp = sp.cut(box(x - 17, x + 17, y0 - 1, y0 + SPINE_T + 1, PAN_Z1 + 160, PAN_Z1 + 240))
        sp = sp.cut(box(121, 159, y0 - 1, y0 + SPINE_T + 1, 186, 224))                  # rev B2: 40 mm fan cut-out E42 (centre-bay supply)
        for sx in (-1, 1):                                                               # rev B3: end notch (castor swivel space + carriage tongue)
            sp = sp.cut(box(sx * nx0, sx * (nx1 + 1), y0 - 1, y0 + SPINE_T + 1, PAN_Z1 - 1, nz1))
        add(f"A03_spine_{'L' if sy > 0 else 'R'}", sp, "EN AW-6082-T6",
            "waterjet 6 mm 6082-T6, tapped M5 rows for the DIN rails on BOTH faces, M3 x 6 deep for the MGN15R castor rails, M6 to pan/deck, M5 for the strap tabs, M6 slots for the spring brackets; end notches |x| 202..262 z 37..128",
            explode=(0, sy * 140, 0), flat=None, notes=f"rev B4: drive notch |x| 73 z 37..130 (spine section above it 208 mm, CALC s.9); structural wall + DIN panel ({'power' if sy > 0 else 'safety/control'} bay outside, centre bay inside); carries the castor springs, guides and tower roofs (rev B3)")
    # spine-plane corner brackets: A06 (FL, rail for U7 + roof), A07 (RR, rail for U8 + roof + deck corner, replaces the RR post), A08 (RL, left HIGH rail end, above the scanner)
    add("A06_corner_bracket_FL", box(SPINE_X, 300, SPINE_Y - SPINE_T, SPINE_Y, TOWER_ROOF[1], DECK_Z0), "EN AW-6082-T6",
        "waterjet 6 mm 6082-T6, splice plate M5 x4 to the spine end, M6 x2 to the deck, M6 x2 to the tower roof; tapped M5 for the corner DIN rail",
        explode=(60, 140, 0), notes="no scanner at this corner: free volume above the tower roof; carries the FL roof (rev B3)")
    add("A07_corner_bracket_RR", box(-340, -SPINE_X, -SPINE_Y, -(SPINE_Y - SPINE_T), TOWER_ROOF[1], DECK_Z0), "EN AW-6082-T6",
        "waterjet 6 mm 6082-T6, splice plate M5 x4 to the spine end, M6 x3 to the deck, M6 x2 to the tower roof; tapped M5 for the corner DIN rail",
        explode=(-60, -140, 0), notes="rev B3: replaces the RR end post (a post at (-360, -106) would hit the RoboPad collector E01)")
    add("A08_rail_bracket_RL", box(-300, -SPINE_X, SPINE_Y - SPINE_T, SPINE_Y, 220, DECK_Z0), "EN AW-6082-T6",
        "waterjet 6 mm 6082-T6, splice plate M5 x2 to the spine end, M6 x2 to the deck; tapped M5 for the left HIGH rail extension",
        explode=(-60, 140, 0), notes="rev B3: above the RL scanner (z >= 220 > housing top 214.5)")
    add("A10_rail_bracket_FR", box(SPINE_X, 300, -SPINE_Y, -(SPINE_Y - SPINE_T), 220, DECK_Z0), "EN AW-6082-T6",
        "waterjet 6 mm 6082-T6, splice plate M5 x2 to the spine end, M6 x2 to the deck; tapped M5 for the right HIGH rail extension (CAN1, SR3)",
        explode=(60, -140, 0), notes="rev B4: right HIGH rail extended to x 298 (SR3 + CAN1 at its real size); above the FR scanner (z >= 220)")
    d = DOUBLER
    add("A09_deck_doubler", box(d["x0"], d["x1"], -(SPINE_Y - SPINE_T), SPINE_Y - SPINE_T, DECK_Z0 - d["t"], DECK_Z0), "EN AW-6082-T6",
        "waterjet 15 mm 6082-T6 doubler under the deck at the column foot: the 8 foot M6 go through deck + doubler into nuts (or M6 tapped in the doubler); M5 x6 to each spine top edge angle",
        explode=(0, 0, 200), flat=(DECK_Z0 - d["t"], d["t"]),
        notes="rev B4 (G-19): CALC s.9 strip b = 62 mm (bolt pitch, lower bound) with deck + doubler; x -160..34 clear of the DSR plates and the cable hole")
    # end posts (deck support at the ends), 30x30x3 tube: rev B3 (+-360, +-106); none at RR (A07 instead)
    px, py = POSTS[0]
    for sx, sy, tag in CORNERS:
        if tag == "RR":
            continue
        x, y = sx * px, sy * py
        add(f"A04_post_{tag}", box(x - 15, x + 15, y - 15, y + 15, PAN_Z1, DECK_Z0)
            .cut(box(x - 12, x + 12, y - 12, y + 12, PAN_Z1 - 1, DECK_Z0 + 1)), "EN AW-6082-T6",
            "30x30x3 square tube EN 755-2, cut + drill; M6 tab for the tower roof", explode=(sx * 60, 0, 0))
    # tower roofs (rev B3): no legs (they were inside the swivel circle). 6 mm S355MC 128..134, carried by the spine stub above the
    # notch (y 137 edge, |x| 202..262), the corner bracket (A06 FL / A07 RR) and the post tab; the PU bump pad of the castor
    # carriage hits its underside right above the castor axis (bump stop, up to 815 N, CALC s.9).
    for sx, sy, tag in CORNERS:
        xmax = 400 if tag in SCAN_TAGS else 340                                         # scanner seat to the corner; else clear of E01 / covers
        rf = box(sx * 202, sx * xmax, sy * SPINE_Y, sy * 400, TOWER_ROOF[0], TOWER_ROOF[1])
        rf = rf.fuse(box(sx * SPINE_X, sx * xmax, sy * (SPINE_Y - SPINE_T), sy * SPINE_Y, TOWER_ROOF[0], TOWER_ROOF[1]))
        if tag != "RR":                                                                  # tab to the post
            rf = rf.fuse(box(sx * (px - 15), sx * (px + 15), sy * (py + 15), sy * SPINE_Y, TOWER_ROOF[0], TOWER_ROOF[1]))
        rf = rf.intersect(poly(outline(COVER_T + 2), 400, 0))
        add(f"A05_tower_roof_{tag}", rf, "S355MC",
            "laser cut 6 mm S355MC roof, bent flange M6 x3 to the spine stub, M6 to bracket/post; bump-pad landing on the castor axis; scanner seat machined (FR/RL)",
            explode=(0, 0, 90), notes="rev B3: legs removed (inside the swivel circle); roof top z 134 unchanged -> scan plane 184.5")


def drives():
    """rev B4 (F4, CERTAINTY.md): ez-Wheel SWD 125 1-stage + external brake at its documented size: wheel D125 x 49.7, coaxial
    body (gearbox, motor, electronics, brake) to L = 196 mm from the wheel outer face (SWD manual v2.0.2 p.28), 7.0 kg. The body
    reaches |y| 60.85, i.e. through the spine notch into the centre bay (rev B3 had an ESTIMATE 190 x 66 x 135 box above the axle).
    Each drive is held by two 8 mm cheek plates D02 bolted to its gearbox flats (M6 fixing points 50 x 100, manual p.28) and to the
    pan; it runs in its own tunnel E43 (tunnels())."""
    r = WHEEL_D / 2
    rb = SWD_BODY_D / 2
    for sy in (-1, 1):
        s_ = 'L' if sy > 0 else 'R'
        yo = sy * (WHEEL_Y + WHEEL_W / 2)                       # wheel outer face
        yw = sy * (WHEEL_Y - WHEEL_W / 2)                       # wheel inner face
        wheel = cyl(r, WHEEL_W, (0, min(yo, yw), r), (0, 1, 0))
        yi = sy * SWD_Y_IN
        body = cyl(rb, abs(yw - yi), (0, min(yw, yi), r), (0, 1, 0))
        add(f"D01_ezwheel_SWD125_{s_}", wheel.fuse(body), "purchased",
            "purchased ez-Wheel SWD 125 EW2A-125HN04B (4:1 1-stage, external brake), safety encoder, CANopen Safety; L 196 mm, 7.0 kg (manual p.28)",
            category="purchased", color=(0.95, 0.55, 0.12), explode=(0, sy * 220, -60), mass=SWD_MASS,
            src="ez-Wheel SWD manual v2.0.2 p.27-28 (SOURCED L 196 mm, 7 kg, wheel 49.7 mm; body D118 cross-section ESTIMATE)")
        keepout(f"D01_connectors_{s_}", box(-50, 50, min(yi, yi - sy * SWD_CONN_KO), max(yi, yi - sy * SWD_CONN_KO), r, r + rb),
                f"D01_ezwheel_SWD125_{s_}", "SWD manual p.20: I/O, 24 VDC, CAN (M12) and USB (M8) connectors in the upper half of the inboard end face; 40 mm for angled plugs + cable bend")
        for sx in (-1, 1):                                      # cheek plates on the gearbox flats (x +-59), pan to above the axle
            add(f"D02_swd_cheek_{s_}{'F' if sx > 0 else 'A'}", box(sx * 60, sx * 68, sy * 140, sy * 200, PAN_Z1, 118), "EN AW-6082-T6",
                "waterjet 8 mm 6082-T6 cheek: 4 x M6 into the SWD gearbox fixing points (50 x 100, manual p.28), 2 x M6 PEM to the pan, angle to the spine",
                explode=(sx * 40, sy * 170, -40))


def tunnels():
    """rev B4 (F3): each SWD body runs in a 2 mm 5754 tunnel E43 that separates it from the side-bay and centre-bay air. Inlet: the
    pan slot under the inboard end (|y| 22..100, room air from under the robot); the slot outboard of |y| 100 carries an EPDM brush
    strip; the outboard baffle (|y| 205..207, D 121 hole + lip seal around the body) closes the tunnel against the wheel well. Outlet:
    the 60 mm tunnel fan E44 on the hood in the side bay (|y| 140..200) blows the tunnel air into the side bay, ahead of the bay exhaust
    fan E40_*out. The SWD housing therefore sees room air (SWD rating 0..+40 C), the drive losses go to the side bay (thermal model,
    electrical/netlist_amr.yaml 'thermal')."""
    T = TUNNEL
    x, t, zt = T["x"], T["t"], T["z_top"]
    zc = WHEEL_D / 2
    for sy in (-1, 1):
        s_ = 'L' if sy > 0 else 'R'
        ya, yb = sy * T["y_end"], sy * (T["y_baffle"] + 2.0)
        y0, y1 = min(ya, yb), max(ya, yb)
        hood = box(-x, x, y0, y1, zt - t, zt)                                                        # roof
        for sx in (-1, 1):
            hood = hood.fuse(box(sx * (x - t), sx * x, y0, y1, PAN_Z1, zt))                          # side walls
        hood = hood.fuse(box(-x, x, min(ya, ya + sy * t), max(ya, ya + sy * t), PAN_Z1, zt))         # inboard end cap
        bf = box(-x, x, min(sy * T["y_baffle"], sy * (T["y_baffle"] + 2)), max(sy * T["y_baffle"], sy * (T["y_baffle"] + 2)), PAN_Z1, zt)
        bf = bf.cut(cyl(SWD_BODY_D / 2 + 1.5, 10, (0, sy * (T["y_baffle"] - 4), zc), (0, sy, 0)))
        hood = hood.fuse(bf)
        hood = hood.cut(box(-29, 29, min(sy * 141, sy * 199), max(sy * 141, sy * 199), zt - t - 1, zt + 1))   # E44 opening (fan sits on the roof)
        add(f"E43_swd_tunnel_{s_}", hood, "EN AW-5754-H22",
            "laser cut + bent 2 mm 5754, riveted; EPDM lip seal at the spine notch, around the SWD body (baffle) and on the pan slot |y| 100..207 (brush strip); "
            "inlet = pan slot under the inboard end, outlet = tunnel fan E44",
            explode=(0, sy * 200, 140), color=(0.80, 0.81, 0.83),
            notes="F3 fix (CERTAINTY.md): SWD 0..+40 C rating vs side-bay air 44-46 C; the SWD now sees room air (TP-11 acceptance in ce/TEST_PLAN.md)")
        add(f"E44_tunnel_fan_{s_}", box(-30, 30, sy * 140 if sy > 0 else sy * 200, sy * 200 if sy > 0 else sy * 140, zt, zt + 25), "purchased",
            "purchased 60x60x25 mm 24 V fan (same type as E40), on the tunnel hood, blows tunnel air up into the side bay", category="purchased",
            color=(0.1, 0.1, 0.11), explode=(0, sy * 200, 200), mass=0.1)


def swivel_profile(margin=5.0, sweep=True):
    """radius of the castor swivel envelope vs body z (CASTOR_SUSPENSION.md s.4): wheel r_w(z) = hypot(F + sqrt(R^2 - (z-40)^2), w/2)
    for z 0..80, fork r 50 z 80..98 (castor frame), swept over the travel -2.5..+17 (sweep=True), plus margin."""
    F, R, hw = CASTER_TRAIL, CASTER_D / 2, CASTER_W / 2
    def rc(zc):
        if 0.0 <= zc <= 2 * R:
            return math.hypot(F + math.sqrt(max(0.0, R * R - (zc - R) ** 2)), hw)
        if 2 * R < zc <= 98.0:
            return CASTER_FORK_R
        return 0.0
    d0, d1 = SUSP_TRAVEL if sweep else (0.0, 0.0)
    def r(z):
        return max(rc(z - d) for d in np.linspace(d0, d1, 40)) if sweep else rc(z)
    return r, margin


def swivel_solid(sx, sy, z0, z1, margin=5.0, sweep=True, dz=1.0):
    """solid of revolution about the castor axis from the profile above (stacked discs, 1 mm steps)"""
    r, m = swivel_profile(margin, sweep)
    cx, cy = sx * CASTER_XY[0], sy * CASTER_XY[1]
    sol = None
    z = z0
    while z < z1 - 1e-6:
        zt = min(z + dz, z1)
        rr = max(r(z), r(zt), r((z + zt) / 2))
        if rr > 0:
            d = cyl(rr + m, zt - z, (cx, cy, z))
            sol = d if sol is None else sol.fuse(d)
        z = zt
    return sol.clean()
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

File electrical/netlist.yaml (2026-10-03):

# Giorgio - electrical netlist / BOM (machine-readable, single source of truth)
# Read by calc.py (checks) and diagram.py (drawing).
# Conventions:
#   source:   URL of the datasheet/manual the value was taken from
#   assumed:  true  -> engineering estimate or recalled value NOT verified against a primary source
#   price_eur: indicative unit price excl. VAT (estimate unless 'price_source' given)
meta:
  project: Giorgio mobile bimanual service robot
  revision: E1.2 (2026-10-03)
  author: electrical design (generated with Claude, to be reviewed by a qualified engineer)
  isc_ka_note: "2.5"

sources:
  openarm_motor: https://docs.openarm.dev/hardware/openarm-2.0/motor
  openarm_safety: https://docs.openarm.dev/overview/safety-guide
  openarm_v1_psu: https://docs.openarm.dev/1.0/hardware/bill-of-materials/procuring-components
  openarm_v1_wiring: https://docs.openarm.dev/1.0/hardware/wiring-and-casing-guide/4-power-can
  openarm_cell: https://docs.openarm.dev/hardware/openarm-cell/general
  dm_j8009p: https://damiao.enactic.ai/en/products/hardware/dm-j8009p-2ec-v1.0
  dm_j8009p_manual: https://github.com/dmBots/DM-J8009P-2EC/tree/HEAD/manual
  dm_j4340p: https://damiao.enactic.ai/en/products/hardware/dm-j4340p-2ec-v1.0
  dm_j4310: https://damiao.enactic.ai/en/products/hardware/dm-j4310-2ec-v1.1/
  mw_ddr480: https://www.meanwell.com/Upload/PDF/DDR-480/DDR-480-SPEC.PDF
  mw_ddr240: https://www.meanwell.com/Upload/PDF/DDR-240/DDR-240-SPEC.PDF
  mw_ddr120: https://www.meanwell.com/Upload/PDF/DDR-120/DDR-120-SPEC.PDF
  mw_ddr60: https://www.meanwell.com/Upload/PDF/DDR-60/DDR-60-SPEC.PDF
  lf_jlln: https://littelfusesales.com/assets/content/vendorAssets/pdf/littelfuse_fuse_jlln_jlls_datasheet.pdf
  lf_tac58: https://www.mouser.com/datasheet/2/240/Littelfuse-Automotive-Blade-Fuse-TAC-ATO-58V-23798.pdf
  sick_nanoscan3: https://www.sick.com/media/pdf/0/80/980/dataSheet_NANS3-CAAZ30AN1_1100334_en.pdf
  tracer_manual: https://static.generation-robots.com/media/user-manual-tracer-2-0-agilex-robotics.pdf
  jetson_agx_orin_ds: https://static.generation-robots.com/media/Jetson-AGX-Orin-Data-Sheet.pdf
  orbbec_336l: https://www.orbbec.com/products/stereo-vision-camera/gemini-336l/
  insta360_x4_power: https://onlinemanual.insta360.com/x4/en-us/faq/specs/battery
  waveshare_p4: https://www.waveshare.com/wiki/RGB-Matrix-P4-64x32
  victron_inverter_smart: https://www.victronenergy.com/upload/documents/Datasheet-Inverter-Smart-1600VA-5000VA-EN.pdf
  nespresso_essenza_mini: https://www.nespresso.com/shared_res/manuals/essenza-mini/2018/UM_ESSENZA_MINI_EN_FNL.pdf
  truck_24v_capsule: https://www.truckstyler-shop.de/Suitable-for-Nespresso-Truck-24V-coffee-capsule-machine?slotID=2
  handpresso_auto: https://www.handpresso.com/en/handpresso-auto-capsule-353.html
  ur_oem_dc: https://www.universal-robots.com/manuals/EN/HTML/SW5_19/Content/prod_oem_cb_all/oem_cb_all_specs_root.htm
  ur_datasheet: https://www.universal-robots.com/media/1826690/01_2023_collective_data_sheet-1.pdf
  elite_cs63: https://www.eliterobots.com/cobots/cs63
  uf850: https://docs.850.ufactory.cc/8.technical_specifications.html
  kinova_gen3: https://www.kinovarobotics.com/uploads/User-Guide-Gen3-R07.pdf
  eu_battery_reg: https://eur-lex.europa.eu/eli/reg/2023/1542/oj
  schaltbau_c195: https://www.schaltbau.com/en/products/contactors/c195/
  robopad: https://docs.galco.com/techdoc/rbtq/robopads_dat.pdf
  tracer_ds: https://static.generation-robots.com/media/datasheet-tracer-2-0-agilex-robotics.pdf

ride_through_v: 28.8          # DDR-480C 100 ms input ride-through limit

# ------------------------------------------------------------------------------------------- battery
battery:
  chemistry: LiFePO4
  series: 15                 # 15s keeps V_max 54.75 V < 60 V; 15s 30 Ah = 1.44 kWh (CAD final, cad/README.md)
  parallel: 5
  cell:
    ref: "LFP 32700 cylindrical 6 Ah power-type cell (EVE/Lishen class), 15s5p = 75 cells in 2 lying layers (32 mm) -> fits 270x400x75 mm, ~10.5 kg cells + BMS/case ~2.5 kg = 13 kg"
    v_nom: 3.2
    v_max: 3.65
    v_min_cutoff: 2.5
    ah: 6
    r_ac_mohm: 6.0           # assumed: lowest plausible ACIR of a 6 Ah 32700 (worst case for Isc)
    r_dc_mohm: 14.0          # assumed: DC-IR incl. ageing (worst case for sag)
    c_cont: 1.2              # REQUIREMENT on the pack spec (32700 power cells are typically rated 2-3 C continuous) [A]
    c_pulse: 2.0             # REQUIREMENT, <= 10 s
    c_charge: 1.0            # assumed max charge C-rate at 15-35 C
    assumed: true
  r_interconnect_mohm: 3.0   # assumed: nickel/copper strip interconnects of a cylindrical pack
  r_bms_path_mohm: 1.0       # assumed: MOSFET BMS + shunt, hot (max)
  r_bms_path_min_mohm: 0.5   # assumed: cold (min) - used for Isc
  usable_dod: 0.90
  bms_component: BMS

tracer:                      # AgileX Tracer 2.0 own battery (separate island)
  v_nom: 25.6
  ah: 30
  usable_dod: 0.85
  charger_component: CHG_TRACER
  source: tracer_manual
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

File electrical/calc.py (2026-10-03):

#!/usr/bin/env python3
"""Giorgio electrical design validation.

Loads netlist.yaml and checks:
  * battery: SELV/PELV limit, EU 2023/1542 2 kWh threshold, charger CV per cell
  * prospective short-circuit current of the LFP pack (from internal resistance)
  * DC-DC sizing vs continuous loads (80 % derating) and simultaneous peaks
  * pack current / C-rate / BMS limits with ALL peaks at once, pack sag vs DC-DC UVLO
  * per-branch wire ampacity (base table x ambient x grouping), voltage drop
    (<3 % power, <5 % elsewhere), fuse selection (In >= 1.25 I_cont, In <= Iz,
    V_dc rating, DC breaking capacity >= Isc at that point, no blow on peaks)
  * contactors: DC break of worst-case current, mirror contacts
  * precharge: tau, time to 95 %, resistor energy and average power
  * regen clamp window on the 24 V arm buses, clamp resistor sizing
  * autonomy for three duty profiles (pack, Tracer, combined with energy balancing)
  * charge time (dock CC/CV, Tracer charged by the onboard isolated charger)
  * coffee options A/B/C: peak current, C-rate, energy per cup, main fuse/cable impact
  * safety functions: PFHd sum vs PL d (unknown/unrated elements -> FAIL)
  * BOM total

Usage:  python3 calc.py [netlist.yaml] [CHECKS.md]      (Python 3 + PyYAML only)
Exit code 1 if any FAIL.
"""
import math
import sys
from pathlib import Path

import yaml

HERE = Path(__file__).resolve().parent
RHO_CU_20 = 0.017241          # ohm mm^2 / m
ALPHA_CU = 0.00393            # 1/K
T_COND = 70.0                 # conductor temperature for voltage drop (PVC max)

results = []                  # (section, item, value, limit, status, note)


def rec(section, item, value, limit, ok, note=""):
    status = "INFO" if ok is None else ("PASS" if ok else "FAIL")
    results.append((section, item, value, limit, status, note))
    return ok


def interp(table, x):
    pts = sorted((float(k), float(v)) for k, v in table.items())
    if x <= pts[0][0]:
        return pts[0][1]
    for (x0, y0), (x1, y1) in zip(pts, pts[1:]):
        if x <= x1:
            return y0 + (y1 - y0) * (x - x0) / (x1 - x0)
    return pts[-1][1]


class Net:
    def __init__(self, path):
        self.d = yaml.safe_load(Path(path).read_text())
        d = self.d
        self.b = d["battery"]
        self.bus = {x["id"]: x for x in d["buses"]}
        self.comp = {c["id"]: c for c in d["components"]}
        self.load = {x["id"]: x for x in d["loads"]}
        self.conv = {x["id"]: x for x in d["converters"]}
        self.fuse = {x["id"]: x for x in d["fuses"]}
        self.br = {x["id"]: x for x in d["branches"]}
        cell = self.b["cell"]
        self.ns, self.np = self.b["series"], self.b["parallel"]
        self.v_nom = self.ns * cell["v_nom"]
        self.v_max = self.ns * cell["v_max"]
        self.v_min = self.ns * cell["v_min_cutoff"]
        self.ah = self.np * cell["ah"]
        self.e_nom = self.v_nom * self.ah
        self.main = d.get("main_bus", "B48")
        mb = self.bus[self.main]
        self.v_min_bus = min(self.v_min, mb.get("v_min", self.v_min)) if d.get("main_bus") else self.v_min

    # ---- resistances
    def r_pack(self, worst):
        c = self.b["cell"]
        r_cell = c["r_ac_mohm"] if worst == "min" else c["r_dc_mohm"]
        r = self.ns * r_cell / self.np + self.b["r_interconnect_mohm"]
        r += self.b["r_bms_path_min_mohm"] if worst == "min" else self.b["r_bms_path_mohm"]
        return r / 1000.0

    # ---- load / converter currents
    def bus_power(self, bus_id, kind):
        return sum(l[f"p_{kind}_w"] for l in self.load.values() if l["bus"] == bus_id)

    def conv_out_current(self, cid, kind):
        c = self.conv[cid]
        i = self.bus_power(c["out_bus"], kind) / self.bus[c["out_bus"]]["v_nom"]
        if kind == "peak":
            i = min(i, c["iout_a"] * c.get("peak_factor", 1.0))
        return i

    def conv_in_power(self, cid, kind):
        c = self.conv[cid]
        return self.conv_out_current(cid, kind) * self.bus[c["out_bus"]]["v_nom"] / c["eta"]

    def excl_saving(self, kind):
        """pack-side W that can never flow together (energy-management interlocks): sum of the smaller members"""
        sav = 0.0
        for g in self.d.get("exclusive", []):
            if "sets" in g:     # groups of loads that never run together: keep only the largest set
                vals = [sum(self.load[l][f"p_{kind}_w"] for l in st) for st in g["sets"]]
            else:
                vals = [self.load[l][f"p_{kind}_w"] for l in g.get("loads", [])]
                vals += [self.conv_in_power(c, kind) for c in g.get("convs", [])]
            sav += sum(vals) - max(vals)
        return sav
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

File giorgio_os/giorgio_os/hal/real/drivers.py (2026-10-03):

"""Real-robot driver STUBS.

Every class documents the exact SDK / ROS 2 interface it will wrap. None of them talks to hardware
yet: methods raise :class:`NotImplementedError` with a pointer to the bring-up step in the README
roadmap. Construction is side-effect free, so the full stack (runtime, API, UI) can be started with
``--backend real`` on a laptop to check wiring/config without hardware.

ROS 2 is accessed through ``rclpy`` from a single executor thread owned by
:class:`RosBridge`; drivers only touch cached messages and action clients, so the giorgio_os
control loop never blocks on DDS.
"""
from __future__ import annotations

from typing import Any, Optional

import numpy as np

from ...types import (ActionHandle, ArmStatus, BaseStatus, BatteryStatus, CoffeeStatus, DockStatus, GripperStatus,
                      Pose2D, RelayStatus, ScanFrame)
from ..interfaces import (ArmDriver, BaseDriver, BatteryDriver, CameraDriver, CoffeeModuleDriver, DockDriver, FaceDriver,
                          GripperDriver, SafetyRelayDriver, SafetyScannerDriver, Trajectory)


class NotBroughtUp(NotImplementedError):
    pass


class RosBridge:
    """Owns rclpy init, one node ('giorgio_os') and a MultiThreadedExecutor spinning in a thread.

    TODO(bring-up step 1): ``rclpy.init(domain_id=cfg.real['ros_domain_id'])``; create node; start executor thread.
    """

    def __init__(self, cfg: dict[str, Any]):
        self.cfg = cfg
        self.node = None            # rclpy.node.Node once started

    def start(self) -> None:
        raise NotBroughtUp("RosBridge.start: rclpy not wired yet (README roadmap, step 1)")
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

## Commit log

2026-10-02 Giorgio v7: open-parts mobile bimanual robot sim (MuJoCo), self-loading logistics, De'Longhi coffee backpack, articulated humans, agent, Blender renders, Kickstarter drafts
    [base_cover.obj, column_cover.obj, crown.obj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]
2026-10-02 Video di presentazione v7: montaggio (compose.py, edit_v7.json), musica sintetizzata, persone colorate nei render, camere
2026-10-02 Giorgio v8: volto LED, cappellino, fascia tricolore, mani open (ORCA, AmazingHand), smistamento, ricarica automatica verificata, pianificatore anti-urto
    - aggancio alla stazione 10/10 (campo di aggancio, colonnina arretrata, stop filtrato)
    - bracci: controllo urti con gli oggetti gia' posati (braccio + oggetto in mano), passaggio alto in linea retta
    - smistamento: contenitori a due posti, posto scelto in esecuzione, presa con apertura parziale: 6/6, zero urti
    - caffe': passaggio della tazzina senza scatto; docs alimentazione e certificazione; verifiche/
    [base_skirt.obj, bumper.obj, coffee_housing.obj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]
2026-10-02 v9: logo (tazzina con la G), macchina del caffe' generica, impianto elettrico nella base, configurazioni, scena di ricarica, diagramma energia, cartello ROS 2
2026-10-02 Logo nuovo (tazzina vista dall'alto = G), posa di presentazione per mani articolate
2026-10-03 giorgio-os: codice unificato (HAL sim/real, abilita', supervisore di sicurezza, energia, agente, console operatore, 29 test); FEASIBILITY.md
2026-10-03 CAD meccanico (CadQuery): ~100 parti, 128 giunti bullonati, validazione interferenze/fori/filetti/carichi/ribaltamento, BOM; sequenza CAD per il video
    [bom_fasteners.csv, bom_parts.csv]
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2026-10-03 Verifiche carene (body_link0 coperto) e collari vs braccia; impaginazione automatica testi; musica: pad, arpeggio, mastering; finale ironico open
    [neck_cover.obj, waist_cover.obj]
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2026-10-03 Elettrico rivalidato sui dati verificati del Tracer, variante MiR250; distinta base unificata (somma parti 32.484 EUR)
    [bom.csv]
2026-10-03 Sim allineata al CAD validato: gusci (busto 105 mm con aperture spalle, carter vita, colonna), masse 135.7 kg, colonna 150 mm, batteria 15s30Ah, scanner nei pod, RoboPad +-5 mm, macchina reale 229 mm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
    [base_skirt.obj, coffee_housing.obj, column_fixed.obj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]
2026-10-03 Verifica gusci sulla mesh di MuJoCo (frame corretto): bracci-busto >= 29 mm; spallacci rimossi (non nel CAD); aperture spalle come CAD (r 82 mm)
    [neck_cover.obj]
2026-10-03 v11: render e montaggio sui dati finali (CAD, elettrico 30 Ah, BOM)
2026-10-03 CAD: mensola caffe' 0.69 m, apertura carter sopra i pulsanti, anello con feritoie, batteria 15s30Ah; rivalidato 0 FAIL. Montaggio v11: dati di validazione finali
    [bom_fasteners.csv, bom_parts.csv]
2026-10-03 Esplosi: base a terra e resto in alto (render), base verso il basso (CAD)
2026-10-03 Confronto basi AgileX (Tracer / Ranger Mini 3.0 / Ranger) con dock del produttore, richiesta ad AgileX, piano di prova del carico
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2026-10-03 Variante Ranger Air (archivio): CAD 59.3 kg 0 FAIL, elettrico 24 V alimentato dalla base, autonomia ~3 h insufficiente
    [bom.csv, bom_fasteners.csv, bom_parts.csv]
2026-10-03 Elettrico RB-THERON: bilancio di potenza completo, verdetti per scenario, BOM 47.778 EUR (base inclusa)
    [bom.csv]
2026-10-03 Sequenza anatomia dal CAD (gruppi accesi uno alla volta, in trasparenza) con didascalie
2026-10-03 Elettrico Ranger Mini 3.0: 166 PASS / 1 FAIL, watt sufficienti con limiti software, autonomia 6.5 h barista; BOM 31.869 EUR (lean 30.949)
    [bom.csv]
2026-10-03 CAD su Ranger Mini 3.0: 85.3 kg / 120, 0 FAIL, limiti di moto 1.5 m/s2; domande ad AgileX sulla velocita' di ricarica
    [bom_fasteners.csv, bom_parts.csv]
2026-10-03 Sim su AgileX Ranger Mini 3.0: base cinematica (4 ruote sterzanti), cover con tricolore, colonna fissa, scanner nei pod, aggancio in retromarcia alla stazione AgileX; verifiche: aggancio 10/10, logis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
    [deck_cover.obj, led_deck.obj, tricolor_deck.obj]
2026-10-03 v11: readable anatomy (light ghost parts, solid highlight), dim schematic behind text
2026-10-03 v12: emotional product cut (no technical/price/wiring sections), music without mandolin, text halo, automatic text-overlap check
2026-10-04 v14: stable exploded labels, visible insertion, box tray/rear rack scenario, trademark NOTICE, new face/ending lines
2026-10-04 Hats (coppola, barista bustina, backwards snapback) replace the red cap; customizable LED faces; paper coffee cup; hide removed Insta360 mast
2026-10-04 Detailed snapback (eyelets, binding, sticker, green underbrim); A/B LED face variants
2026-10-04 LED faces: clearly different B variants for skeleton, binocular, LED mask and neon
2026-10-04 Hats fit the head without interpenetration (convex-hull check, rigid lift + residual push); bustina default hat
2026-10-04 Snapback: drop brim stitch rings (looked like loose wires)
2026-10-04 Torso shell: smooth shoulder openings snapped to the CAD cylinder + rubber grommet; v16 re-render
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2026-10-05 Own AMR base (rev B4), video series v19, open-source licences
    - amr/: our own CE-oriented mobile base: CadQuery CAD (170 parts, keep-out checks), calculations,
    electrical + safety package (SICK nanoScan3, Pilz PNOZmulti 2, ez-Wheel SWD), CE technical-file
    skeleton, BOM + Italian industrialisation plan, verification and certainty audit, datasheet
    - simulation: giorgio_model.py uses the own base by default (BASE = "amr_revB")
    - render: --newbase/--newdock in blender_render.py, video series (teaser, components, activities,
    training, customisation, long) via video_series.py
    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
    [A01_floor_pan.dxf, A01_floor_pan.step, A01_floor_pan.stl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]
2026-10-06 Move one-off and superseded root scripts into legacy/
    Nothing current imports them; legacy/README.md says what each one was.
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2026-10-06 Docs: BOM by subsystem, customisation guide, glossary of Italian names
    docs/BOM_OVERVIEW.md (generated by scripts/bom_overview.py from amr/bom_amr.csv + docs/bom.csv): component costs
    only, grouped by subsystem with part numbers, sources, status and subtotals; rows replaced by the own AMR are listed
    and not double-counted.
    [bom_overview.csv]
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

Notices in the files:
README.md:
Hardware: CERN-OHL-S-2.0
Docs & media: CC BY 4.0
